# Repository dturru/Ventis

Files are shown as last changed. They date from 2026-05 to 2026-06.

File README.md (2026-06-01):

# Ventis

Smart window-ventilation device for dorm rooms. An ESP32 reads CO₂ / temperature / humidity
(SCD40), runs a control loop, and serves a phone-facing dashboard over its own WiFi AP. The
dashboard shows live air quality, trends, and a first-person AI mascot ("Dodi") that explains
what's happening and what the device is doing.

---

## Repo map

```
Ventis/
├── firmware/              ESP32 application (PlatformIO)
│   ├── src/main.cpp       sensors + control loop + web server + THE DASHBOARD (embedded)
│   ├── src/main_sim.cpp   simulation build variant
│   ├── include/           config.h, secrets.h.example  (copy to secrets.h, never commit secrets)
│   ├── platformio.ini     build config
│   └── wokwi.toml         Wokwi simulator config
├── dev/                   FRONTEND DEV HARNESS  ← do UI work here (no hardware needed)
│   ├── index.html         standalone copy of the dashboard
│   ├── serve.py           local server that mocks the device's HTTP endpoints
│   ├── mock-*.json        fake device data (data / history / insight)
│   ├── generate_mocks.py  regenerate the mock CO₂ story
│   └── README.md          dev-harness details
├── outdoor-node/          SEPARATE firmware for the outdoor sensor node (not the dashboard)
├── cad/                   hardware CAD
├── marketing/             posters, booth card
└── README.md              you are here
```

---

## `main.cpp` at a glance — what each block is

`firmware/src/main.cpp` is one file (~1,725 lines) but it's cleanly divided by
`// ── Section ──` header comments. Here's what each block is and its category:

| Lines | Section | What it does | Category |
|---|---|---|---|
| 1–18 | includes + helpers | libraries (WiFi, SCD40, SSD1306 OLED, async web server) + `toF()` | setup |
| 21–28 | **Sensors** | SCD40 / DS18B20 / OLED / web-server object declarations | sensors |
| 29–118 | **State** | global `readings` struct, mode switch, history ring buffer, insight timers | state |
| 119–177 | **Control logic** | fan decision (`evaluateFan`), duty %, **fan PWM output**, history push | control |
| 178–201 | **Google Sheets logger** | POSTs readings to the Sheets web-app for data logging | networking |
| 202–229 | **RGB LED** | CO₂-colored status LED — green / amber / red | hardware |
| 230–253 | **OLED** | draws the 128×64 status screen (CO₂, temp, fan, IP) | hardware |
| 254–466 | **/insight helpers** | builds Dodi's AI text; calls the Anthropic API (offline fallback if no key/WiFi) | backend (AI) |
| **469–1385** | **`INDEX_HTML`** | **the dashboard — HTML + CSS + JS served to phones** | **FRONTEND** |
| 1387–1537 | setupServer + auto-insight | HTTP routes: `/`, `/data`, `/history`, `/control`, `/insight`, `/log/*` | backend (API) |
| 1538–1639 | **Setup** | boot sequence: pin/PWM init, OLED, SCD40, DS18B20, **WiFi connect + AP**, start server | wifi / init |
| 1640–1725 | **Loop** | the heartbeat: read sensors → control → push history → log → redraw OLED → update LED | orchestration |

> Line numbers drift as the file is edited — jump by searching for the `// ── ` section headers
> (e.g. `// ── OLED ──`). **For UI work you only care about the one bold row (`INDEX_HTML`),** and
> even then you edit `dev/index.html`, not this file. Everything else is firmware/backend.

---

## Where the frontend lives (read this first)

This is an **embedded** project, so there is **no React app and no `src/components/` folder**.
The dashboard is a single hand-written HTML/CSS/vanilla-JS page that exists in **two places that
must be kept in sync**:

1. **`dev/index.html`** — the standalone, browser-runnable copy. **Do all UI work here.**
2. **`firmware/src/main.cpp`** — the canonical copy, embedded as a C++ string named `INDEX_HTML`
   (a `R"raw( ... )raw"` literal) that the ESP32 actually serves to phones. **Source of truth on
   the device.**

Inside `main.cpp`, the dashboard is the block from `INDEX_HTML[] PROGMEM = R"raw(` to
`</body></html>)raw";` (currently ~line 469 to ~line 1385). Within that block:

| Part | Find it by searching for |
|---|---|
| All CSS | `<style>` … `</style>` |
| HTML markup | between `</style>` and the first `<script>` |
| All JS (render, sidebar, trend chart, Dodi bubbles) | `<script>` … `</script>` |

> Search for those anchors rather than trusting line numbers — they shift as the file is edited.
> Everything **outside** that block in `main.cpp` is backend C++ (sensors, control loop, the AI
> `/insight` text generator ~line 254, and the `server.on(...)` HTTP routes ~line 1388). You do not
> need to touch any of it for UI work.

---

## Dev workflow (no hardware required)

```bash
cd dev
python serve.py
# open http://localhost:8000/?mock=1   (the ?mock=1 is required — it loads mock-*.json)
```

Edit `dev/index.html`, reload the browser, iterate. The mock server fakes every endpoint the page
calls, so the JS behaves exactly as it does on the device.

To change the demo CO₂ story (the numbers the page animates through), edit the curve functions in
`dev/generate_mocks.py`, run `python generate_mocks.py`, and reload.

### Getting your changes onto the device

There is **no build step that does this automatically.** When your UI is ready, copy the final HTML
from `dev/index.html` back into the `INDEX_HTML` block in `firmware/src/main.cpp` (between the
`R"raw(` and `)raw"` markers), then flash. Keep the two files identical. *(Automating this
round-trip is a known TODO.)*

---

## The endpoint contract (what the page talks to)

The JS in the dashboard calls these device endpoints. The dev server (`serve.py`) mocks all of them,
so you can develop against the same shapes:

| Endpoint | Method | Purpose |
|---|---|---|
| `/data` | GET | current readings (co2, tempIn, humidity, tempOut, fanOn, duty, logging state) |
| `/history` | GET | ring buffer of recent samples for the trend chart |
| `/insight` | GET / POST | the AI mascot's current text (GET) / regenerate it (POST) |
| `/control` | POST | manual override + setpoint (controller mode only) |
| `/log/start`, `/log/stop` | GET | start/stop Google-Sheets logging |

Control actions only fire from a controller session (the dashboard is opened with `?ctl=1`);
plain viewers are read-only. See `mock-data.json` / `mock-history.json` for exact field shapes.

---

## Branches & the booth fallback

- **`main`** — current dashboard + dev harness. **Branch off this.**
- **`booth-fallback`** (git tag) — the proven Technigala-booth build. If a change breaks the live
  demo, recover with `git checkout booth-fallback` and flash. It is not a branch; it is a permanent
  bookmark to the known-good commit.
- `dodi-pixel-art` — Dodi mascot sprite work.

---

## Firmware build (only when flashing real hardware)

PlatformIO project in `firmware/`. Copy `include/secrets.h.example` to `include/secrets.h` and fill
in WiFi + (optional) Anthropic API key before building. `platformio.ini` defines the board/env.
UI contributors do **not** need this — the `dev/` harness covers all dashboard work.

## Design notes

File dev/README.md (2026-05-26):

# Ventis dev — browser preview of the web UI

This folder lets you preview the Ventis web UI in a browser without flashing the ESP32. The `index.html` here is a copy of the `INDEX_HTML` PROGMEM string in `firmware/src/main.cpp`. The `serve.py` script is a tiny HTTP server that mocks the ESP32's endpoints (`/data`, `/history`, `/insight`, `/control`) so the JS behaves identically.

## Quick start

```bash
cd dev
python serve.py
```

Then open: <http://localhost:8000/?mock=1>

The `?mock=1` query parameter tells the JS to fetch from `/mock-*.json` files instead of the live device endpoints. Without it, the page tries to hit `/data` and `/history` (which the dev server doesn't serve as live endpoints), so always include it.

## Files

| File | Purpose |
|---|---|
| `index.html` | Standalone copy of the firmware web UI — must be kept in sync with the `INDEX_HTML` string in `firmware/src/main.cpp` |
| `serve.py` | Dev HTTP server (port 8000 by default; `python serve.py 8080` for custom port). Serves static files and fakes POST `/insight` + POST `/control` |
| `generate_mocks.py` | Regenerates the three mock JSON files. Run once, or whenever you want to tweak the demo CO2 narrative |
| `mock-data.json` | One current-readings snapshot (mirrors `GET /data`) |
| `mock-history.json` | 60-sample ring buffer with a CO2 narrative arc (baseline -> rise -> alarm -> recovery -> settle) — mirrors `GET /history` |
| `mock-insight.json` | Sample Claude API response (mirrors `POST /insight`) |

## Editing the demo CO2 story

Open `generate_mocks.py` and tweak the `co2_curve()`, `temp_curve()`, or `humidity_curve()` functions. Then:

```bash
python generate_mocks.py
```

Reload the browser to see the new story.

## Keeping `index.html` in sync with the firmware

If you edit the web UI in `firmware/src/main.cpp` (the `INDEX_HTML` PROGMEM string), copy the same HTML content into `dev/index.html` so the browser preview stays accurate. A future build-step refactor could auto-generate `index.html` from the firmware source; for now, manual sync.

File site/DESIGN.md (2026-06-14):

# Ventis — Design & Voice Guide

The design system and writing standard for the Ventis site (`site/`). This is
the source of truth: the site reads intentional, not vibe-coded, because the
decisions below are deliberate and documented. When you change the site, change
this doc too.

Tokens referenced here are defined in `src/global.css` (`:root`). Component
classes referenced here exist in that file. Keep the two in sync.

---

## 1. Brand & personality

Ventis makes an invisible problem visible and acts on it. The personality
follows from that:

- **Honest before impressive.** We show the negative control (East Wheelock),
  state the winter limitation, and never fabricate a number. Credibility is the
  product — the dataset and the candor are the moat.
- **Calm, technical, editorial.** Closer to a well-edited field report than a
  startup splash page. Confident, specific, unhurried.
- **Warm, not cute.** Dodi (the mascot) carries the warmth so the prose doesn't
  have to strain for it.

Tagline: **Senses · Ventilates · Explains.** Three verbs, in that order — it
also maps to the product loop and the How-It-Works page.

---

## 2. Voice & tone (also the copy standard)

The site's copy is strong when it's **specific and plain**. It drifts toward an
"AI-generated" feel when it leans on a few rhetorical crutches. Rules:

**Do**
- Lead with the concrete: a number, a room, a moment ("1,111 ppm in a Little
  Hall single, four hours past the line").
- Vary sentence length and rhythm. Let short declaratives land.
- Use plain connectives (period, comma, "and", "but") most of the time.
- Trust the reader. State the point once, well.

**Avoid (the AI-tells)**
- **Em-dashes: default to none in body copy.** This is the single biggest tell,
  and the bar is essentially zero, not "one per paragraph." Use a period, comma,
  colon, or the middot "·" for label separators (e.g. run names, the tagline). A
  rare em-dash in a citation is tolerable; if you're reaching for one in prose,
  restructure the sentence. (Run `grep -rn "—" site/src` before shipping copy.)
- **The "It's not X, it's Y" / "X vs. Y" antithesis on repeat.** It's punchy
  once per page. Three times is a tic. Vary it.
- **"honest / honestly" as a verbal crutch.** Demonstrate candor (show the
  negative control); don't keep announcing it. Aim for ≤1 use per page.
- **Triadic "no X, no Y, no Z" lists** more than once in a stretch.
- **Throat-clearing** ("It's important to note", "In today's world").
- **Generic startup-speak** ("seamless", "revolutionary", "game-changing",
  "we're on a mission").

**Mechanics**
- Curly quotes and apostrophes (`'` `'` `"` `"`), not straight.
- "CO₂" with subscript; "ppm" lowercase; "ASHRAE 1,000 ppm" as written.
- Numbers: thousands separators ("1,111 ppm"). Temperatures in °F on-screen.
- No emoji as UI or as bullets/eyebrows. Use the SVG icon set (§6).

**Claim integrity (non-negotiable)**
- Every CO₂ figure, citation, and product claim on the site must trace to real
  measured data or a cited source. Never round a measurement for punch. The
  data page numbers come from `runs.json` (generated by
  `scripts/extract_runs.py` from the real CSVs) — don't hand-edit them.
- Roadmap language: v2 = "first units expected Fall 2026" framed as a target,
  not a guarantee. No pricing anywhere.

---

## 3. Color

Defined in `:root`. Green is the brand; the CO₂ tiers are semantic and must keep
their meaning everywhere they appear.

**Brand greens** — `--green #1e6e3a` (primary), `--green-deep #155026`,
`--green-darker #0d4520`, `--green-soft #e8f5e9`, `--green-mist #f1f7f1`.

**Semantic air tiers** (CO₂ state — never repurpose these hues for decoration):
- Green `--green` — fresh / good (< ~800 ppm)
- Amber `--amber #b87900` (`--amber-soft #fff7e0`) — elevated / getting stuffy
- Red `--red #c6422c` (`--red-soft #fef2ef`) — high / over ASHRAE 1,000

**Neutrals** — `--bg #f4f7f3`, `--bone #faf9f6`, `--tile #ffffff`,
`--ink #16241a`, `--muted #5e6b5e`, `--faint #8a958a`, `--line` / `--line-soft`.

> The device-demo phone (`.device-screen`) re-scopes a slightly different token
> set to match the on-device app exactly (`--red #c62828`, `--border #d0dbd0`,
> etc.). That mismatch is intentional — it mirrors the ESP32 app, not the site.

**Contrast:** body and UI text must clear WCAG AA (4.5:1). `--muted` on `--tile`
passes; never put `--faint` on tinted fills for anything load-bearing.

---

## 4. Typography

Three roles, set in `:root`:

- **`--serif` DM Serif Display** — display only: hero wordmark, `.section-title`,
  `.evidence-title`, big stat numerals (`.point-k`). Never body.
- **`--sans` Outfit** — everything functional: body, lede, labels, buttons, nav.
- **`--mono` DM Mono** — data and machine voice: chart ticks, peak readouts,
  clocks, the device CO₂ number.

Scale uses `clamp()` for fluid sizing (see `.section-title`, `.lede`,
`.sticker-word`). Keep the eyebrow → title → lede rhythm at the top of each page.

---

## 5. Layout, spacing, elevation

- Container `.wrap` max-width `--maxw 1080px`; prose pages narrow to 860–900.
- Radii: **moderate** (`--r-lg 12 / --r-md 10 / --r-sm 8`, set 2026-06-13 "bolder pass" — dialed back from the all-`0` sharp experiment, which read as too many hard corners). Pills/chips/badges stay fully rounded (`999px`); device-demo phone + true circles unchanged. Elevation is **hairline-led**: crisper `--line` (0.16) + flatter resting shadows; lift on hover.
- Shadows: `--shadow-sm` / `--shadow` / `--shadow-lg` — soft, green-tinted, never
  harsh black. Elevation rises on hover, not at rest.
- Page rhythm: `eyebrow` (12px, tracked, green) → `section-title` → `lede`.

---

## 6. Components & iconography

Reusable primitives in `global.css`: `.panel` (hero nav cards), `.card`,
`.callout` (+ `.amber`), `.points-grid`/`.point`, `.evidence` block,
`.btn`/`.btn-primary`/`.btn-ghost`, `.flow` (how-it-works), `.cta-card`,
`.device-*` (demo).

**Icons:** custom Lucide-style SVGs via `components/Icon.tsx`, set in tinted
`.ico-badge` squares. **No emoji as icons** — this was a deliberate pass; don't
regress to emoji eyebrows or bullets.

---

## 7. Motion

- Transitions **150–300ms**, `ease`. Used for hover lift, tier color crossfades,
  bar fills.
- Entrances: `fade-up` on `.page`; the hero staggers (sticker→sub→air→actions→
  panels). Ambient: hero Dodi `dodi-float` (bob) + periodic **wing-flap & blink**
  (`dodi-wing-l/r`, `dodi-eyes`; reduced-motion-gated).
- **Scroll reveals** (`reveal-up`, §12): below-fold content on non-hero pages rises
  in as it enters the viewport, via CSS scroll-driven `animation-timeline: view()`
  (no JS). Wrapped in `@media (prefers-reduced-motion: no-preference)` +
  `@supports (animation-timeline: view())`, so it degrades to fully-visible — never
  a blank section. Hero + device demo excluded (they own their motion).
- Demo Dodi (`DodiMascot.tsx`) reacts to live state: breathing bob, emotion eyes
  (calm/alert/distress by CO₂ tier), wing-flap while the fan runs.
- **Always gate motion behind `@media (prefers-reduced-motion: reduce)`** — the
  Dodi animations already do. Any new looping animation must too.

---

## 8. Accessibility checklist (per change)

- [ ] Text contrast ≥ 4.5:1 (3:1 for ≥24px bold).
- [ ] Interactive elements are real `<button>`/`<a>`, keyboard-reachable, with a
      visible focus state. (Global `:focus-visible` square green ring lives in
      `global.css` as of 2026-06-13 §12; `accent-color: var(--green)` on native controls.)
- [ ] Images have descriptive `alt`; decorative SVGs `aria-hidden`.
- [ ] Looping/auto motion respects `prefers-reduced-motion`.
- [ ] Tap targets ≥ ~40px on the controls people actually use.

---

## 9. Pre-ship checklist

Adapted from the UI/UX pre-delivery discipline + Ventis specifics. Run before any
push to `main` (which auto-deploys to Vercel).

- [ ] `npm run build` passes (tsc + vite, no type errors).
- [ ] Render-verified in the browser at the route you changed — not just a green
      build. Check mobile width (≤640px) too.
- [ ] No emoji as icons; SVG icon set used.
- [ ] Transitions 150–300ms; reduced-motion respected.
- [ ] Contrast + focus states intact (§8).
- [ ] Responsive at 375 / 768 / 1024 / 1440.
- [ ] **Copy passes §2** — em-dash density low, no repeated "X vs Y", "honest"
      ≤1/page, no emoji eyebrows.
- [ ] **Every number and claim traces to real data / a cited source** (§2).
- [ ] No pricing; v2 framed as a Fall 2026 target.

---

## 10. Influences

Quality bar informed by the `ui-ux-pro-max-skill` pre-delivery checklist
(no-emoji-icons, 150–300ms transitions, 4.5:1 contrast, reduced-motion,
375/768/1024/1440 breakpoints) and anti-patterns (no AI purple/pink gradients;
no harsh neon). Ventis intentionally diverges toward a quiet editorial palette
rather than a trendy style — the credibility of the data is the aesthetic.

---

## 11. 2026-06-10 — craft pass + data-library parity

**Site (dialed-up field report):**
- **Hero air-moment** (`components/HeroAirMoment.tsx`, `.air-moment`): the one
  signature data element. A real measured overnight CO₂ rise (the Little Hall
  single, 1,111 ppm, ~4 h over the line) draws on, and the readout counts up from
  a calm baseline with its color crossing green to amber to red as it passes
  ASHRAE 1,000. Count-up and draw both honor `prefers-reduced-motion`. Numbers
  trace to real data (§2).
- **Paper grain** (`body::after`): a faint fractal-noise overlay over the air
  gradients for warmth and depth. **Warmer `--bone`** (`#faf8f2`).
- **Hero entrance stagger**: sticker → sub → air-moment → actions → panels, ~80ms
  apart; reduced-motion safe.
- **`.pullquote`**: serif editorial accent, available to prose pages.

**Data library (`library/`)** now shares this exact system (DM Serif / Outfit /
DM Mono, the semantic air tiers, the atmospheric backdrop, the card + shadow
language). It was a Vite starter (system font, purple accent, inline-styled
tables); it is now a branded data product with a glassy header, CO₂-tier run
chips, mono numerals, and editorial SOP pages. The same voice and claim-integrity
rules apply there. Tokens live in `library/src/theme.css`, kept in sync with this file.

---

## 12. 2026-06-13 — Impeccable craft layer

A second layer of design parameters, adopted from the Impeccable design skill
(`pbakaus/impeccable`). We take its **brand-agnostic craft discipline and
anti-slop bans** and **preserve our own brand** (green editorial; DM Serif /
Outfit / DM Mono; semantic air tiers). We do **not** adopt Impeccable's own
"Neo Kinpaku" gold/lacquer identity. Where Impeccable already overlaps §§3–10,
the existing rule stands; this section is only the *delta* plus two explicit
conflict resolutions. Apply it on every change, alongside the §9 pre-ship list.

### Deltas (new rules — not already covered above)

**Typography**
- **Line length 65–75ch** on any prose/body block. Add `max-width` in `ch` to
  long-text containers; don't let lede or paragraph copy run full-width.
- **`text-wrap: balance` on h1–h3**; **`text-wrap: pretty` on long prose** (kills
  orphans). Cheap, global, high-yield.
- **Display letter-spacing floor ≥ -0.04em.** Hero/`.section-title`/`.sticker-word`
  may tighten for optics but never below -0.04em (letters touch = cramped, not
  designed). The hero clamp ceiling is **≤ 6rem / 96px** — `.sticker-word` is at
  the limit (`clamp(52px,11vw,96px)`); hold it, don't raise.
- **Placeholder text needs 4.5:1 too** (same as body) — not the muted-gray default.

**Layout**
- **Cards are the lazy answer.** Reach for a card only when it's truly the best
  affordance. **Nested cards are always wrong** — flatten to sections, dividers,
  or tinted bands. Audit `.card`/`.panel` density on each page; if a grid is just
  identical icon+heading+text cards repeated, redesign the rhythm.
- Responsive grids without breakpoints: **`repeat(auto-fit, minmax(280px, 1fr))`.**
- **Semantic z-index scale** (in `:root`): dropdown → sticky → modal-backdrop →
  modal → toast → tooltip. **No arbitrary `999` / `9999`.**
- Flexbox for 1D, Grid for 2D. Don't default to Grid when `flex-wrap` works.

**Motion** (extends §7)
- Prefer **ease-out exponential** curves (`ease-out-quart/quint/expo`) over plain
  `ease` for entrances. **No bounce, no elastic.** Reduced-motion fallback stays
  mandatory (§7).
- Reveal animations must **enhance an already-visible default** — never gate
  content visibility on a class-triggered transition (it never fires on hidden
  tabs / headless renders → blank section).

### Absolute bans (match-and-refuse — rewrite the element if you're about to ship one)

- **Side-stripe borders** — `border-left/right` > 1px as a colored accent on cards,
  callouts, or alerts. Use full borders, background tints, or a leading icon/number.
  (Our `.callout.amber` must use a full tint/border, not a left stripe.)
- **Gradient text** (`background-clip:text` + gradient). Solid color; emphasis via
  weight/size.
- **Glassmorphism as default.** Permitted exactly where it already is and no more:
  the nav header (`global.css` `backdrop-filter`) + the library glassy header are
  "rare and purposeful." **Do not add new glass.**
- **The hero-metric template** (big number / small label / supporting stats /
  gradient accent). Our hero air-moment is a *real measured* signature element,
  not this SaaS cliché — keep it that way.
- **Identical card grids** repeated endlessly.
- **Numbered section markers as scaffolding** (`01 · About / 02 · Process`). Only
  when the section genuinely IS an ordered sequence.
- **Text that overflows its container** at any breakpoint. Test heading copy at
  375/768/1024/1440; if it overflows, lower the clamp max or rewrite the copy.

### Conflict resolutions (Impeccable vs. our existing system)

1. **Eyebrows — KEEP, with discipline.** Impeccable flags the tracked-uppercase
   eyebrow above *every section* as its #1 slop tell, but exempts "one named kicker
   as a deliberate brand system." Our eyebrow → title → lede is exactly that: a
   documented, page-level brand rhythm (§5). **Resolution:** the eyebrow stays as a
   **page-top** device. Do not sprinkle it above every sub-section within a page,
   and never let it be the *only* hierarchy signal. Audit pages with 2+ eyebrows.
2. **Glass — KEEP the two we have, freeze the count.** See the glassmorphism ban
   above: the nav + library headers are purposeful; no new instances.

### The AI-slop test (review heuristic for new work)

Before shipping a new page/section, run the category-reflex check at two altitudes:
- **First-order:** could someone guess the theme + palette from the category alone
  ("air-quality startup → green + clean")? If yes, the first reflex won.
- **Second-order:** could they guess it from category-plus-anti-reference
  ("air-quality but not generic-green → ...")? If yes, the trap one tier deeper won.
Our defensible answer is the **editorial field-report** posture (§1): the
credibility of the data is the aesthetic. Keep proof in front; don't let styling
hide it.

### 2026-06-13 — sharp-corner pass (bolder)

A deliberate move from soft to **sharp**: all radius tokens → `0`, and every
hardcoded rectangular radius squared (nav, buttons, icon badges, pills/tags →
square editorial tags, tooltip, hero sticker). This sharpens the field-report
posture and reads more technical/instrument-like.

- **Kept curved (intentional exceptions):** the device-demo phone frame + its
  internal UI (`.device-*` / `.dd-*`) because it represents physical hardware; a
  sharp "phone" reads as broken, not designed (same spirit as the §3 device-token
  exception). True circles (status dots, the round avatar) are circles, not
  corners — also kept.
- **Motion:** added `--ease-out: cubic-bezier(0.16, 1, 0.3, 1)` (ease-out-expo)
  and applied it to nav/button transitions. Sharp corners + crisp exponential
  motion cohere. Reduced-motion rules (§7) still apply.
- New default: **don't reintroduce `border-radius`** on rectangular surfaces. Use
  `var(--r-*)` (now 0) so the decision stays centralized.

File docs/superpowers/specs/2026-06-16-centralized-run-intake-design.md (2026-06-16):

# Centralized Run Intake — "Run Launcher" Design

**Date:** 2026-06-16
**Status:** Approved design (brainstorming → spec)
**Owner:** Diego (remote) / cofounder (on-campus operator)

## Problem

Starting a data-collection run today touches several disconnected surfaces:

1. The **condition label** is set on the device (telemetry `run`/`condition`) **and** typed again into the **consent** submission — independently.
2. `reconcile_consent.py` fuzzy-matches the two by `canonical(condition)` + nearest start time (±36 h).
3. When the two labels diverge (post-brownout restart re-typed a glued `oneperson`, etc.) the match fails → **orphaned consent**, the exact bug class fixed in PRs #15 and #25.

The operator also hops between the Google Sheet, the consent form, and manual run notes. We want **one gated submission** that records consent, sets the run condition, starts the device, and captures run notes — with the condition **single-sourced** so divergence is structurally impossible.

## Goals

- One cofounder-facing, gated action starts a fully-described, consented run.
- The condition label is composed once from structured fields and used for **both** the device control tab and the consent row → identical by construction → deterministic reconcile.
- A **preflight checkpoint gate** blocks a run when starting it would create a problem, but allows an **audited override** for problems that are safe to fix after the run (orphaned/deferred consent being the canonical case).
- Firmware is **unchanged** — it already polls the Apps Script control tab.

## Non-Goals

- Occupant self-serve / public form (operator is cofounder-only, behind Cloudflare Access).
- Changing how the device polls or how telemetry is written.
- Replacing `reconcile_consent.py` (it stays; it just stops failing because labels can't diverge).

## Architecture (Approach A — page in the gated `library/` app)

The Run Launcher lives in `library/`, which is already behind Cloudflare Access and already has Pages Functions talking to Supabase (`functions/api/annotate.ts`). No new deploy target or Access config.

```
[Cofounder phone]
  RunLauncherPage.tsx  (gated by Cloudflare Access)
        │ POST /api/run-launch  {fields, action, nonce, overrides[]}
        ▼
  functions/api/run-launch.ts  (Pages Function; holds secrets)
        │  1. compose canonical label (label.ts)
        │  2. preflight(...)  → verdicts (pure: preflight.ts)
        │  3. gate: hard-block abort | soft-block needs override | proceed
        │  4. insert consent  → Supabase (postgres.js)        [S3]
        │  5. start device    → Apps Script control doPost     (token)
        │  6. persist launch record (override flags + reason)
        ▼                                   ▼
  Supabase  consent_submissions      Google Sheet `control` tab
  + run_launches                      (logging, label, seq++)
                                            ▼ device polls doGet (existing)
                                      Device starts run, telemetry tagged
                                      with the SAME canonical label
```

### Components

| Component | Path | Responsibility |
|---|---|---|
| `RunLauncherPage.tsx` | `library/src/components/` | Form + live preflight checklist + Start/Stop. Visual/UX — see open questions. |
| `run-launch.ts` | `library/functions/api/` | Orchestrator: compose → preflight → gate → consent insert → device start → launch record. Holds `SUPABASE_DB_URL` + `CONTROL_TOKEN`. |
| `preflight.ts` | `library/functions/api/` | **Pure planner** (mirrors `plan_reconcile`): inputs → per-checkpoint verdicts + tier. Independently unit-tested. |
| `label.ts` | `library/src/lib/` + shared | Compose structured fields → canonical label; reject invalid combos. Mirrors `reconcile_consent.canonical()` rules so output is canonical by construction. |
| Apps Script control write | `firmware/sheets/Code.gs` | Extend `doPost` with `action:"control"`: token-auth (reuse `SHEETS_TOKEN`), set `control` tab `logging`/`label`, bump `seq`. Only genuinely new backend piece. |
| `run_launches` table | `site/scripts/supabase_schema.sql` | Audit row per launch: label, times, consent status, override flags + reason. The "needs attention" surface. |

## Canonical label (the divergence killer)

Structured fields → one string, used everywhere:

- **building** — dropdown of known buildings (`fahey`, `choates`, `little`, `east_wheelock`, …). Closed set.
- **scenario** — dropdown (`window`, `windowclosed`, `fan`, `baseline`, `negcontrol`, …). Closed set.
- **occupancy** — stepper emitting a **digit** (`1`, `2`, …) → `Nperson`. Never a spelled-out word.

Composed: `building_scenario_Nperson` (e.g. `fahey_window_1person`). The composed string must round-trip through the shared `canonical()` unchanged (a hard checkpoint). Because the *same* string is written to the control tab (→ device telemetry `condition`) and to `consent_submissions.condition`, `canonical()` of both is trivially equal and `match_run` is deterministic. The occupancy-as-digit rule encodes the convention from PR #25's follow-up directly into the UI.

## Preflight checkpoint gate

Run server-side in `preflight.ts`. Two tiers.

### Hard blocks — never overridable (cheap to fix, root-cause preventers)

- **H1 Authenticated** — `Cf-Access-Authenticated-User-Email` present (verified founder, as in `annotate.ts`).
- **H2 Valid canonical label** — building ∈ set, scenario ∈ set, occupancy is a positive integer; composed label round-trips through `canonical()` unchanged.
- **H3 Consent captured** — `attested_by`, `consent_method`, `terms_version` present (the *act* of consent is recorded; whether it *persists* is S3).

If any hard block fails: **abort with no mutation**, return what to fix. Start stays disabled.

### Soft blocks — overridable with explicit reason (logged, flags run for follow-up)

- **S1 Device online** — device posted telemetry within `DEVICE_FRESH_WINDOW` (default 90 s ≈ 3× the ~30 s cadence). Stale → telemetry may orphan. Override: device may catch the `seq` on reconnect.
- **S2 No active run** — control tab `logging` already true / a `run_id` active. Override: intentional restart (the post-brownout case).
- **S3 Consent persisted** — the Supabase insert succeeded. Failure (pooler timeout — LESSON (a)) → override "defer consent": start the run, flag consent pending, backfill later. **Reconcile links it automatically by the identical canonical label + time.** This is the override the user explicitly asked for.
- **S4 Duplicate guard** — identical canonical label launched within `DUP_WINDOW_H` (default 6 h). Override: legitimate repeat.

Override mechanics: each soft block surfaces in the form; the operator types a **reason** and confirms "Override & start." Every overridden run writes a `run_launches` row with the overridden checks + reason + timestamp, so it surfaces in a "needs attention" view (Curate/Coverage). **An override is a tracked follow-up, never a silent bypass.**

## Data flow & sequencing (orphan-safe)

1. Compose canonical label.
2. Run non-mutating checks: H1–H3, S1, S2, S4.
3. Attempt consent insert → result feeds S3.
4. **Gate:** any HARD fail → abort, no device start. Only SOFT fails and not overridden → abort, offer override. Clean or fully-overridden → proceed.
5. Start device: Apps Script control `doPost` (`logging=true`, `label`, `seq++`).
6. Persist `run_launches` record (label, started_at, device_last_seen, consent_status, override_flags, reason, nonce).

**Self-healing:** device-condition and consent-condition are the same canonical string, so `reconcile_consent` links them deterministically. Even a deferred-consent (S3 override) run reconciles automatically once consent is backfilled with that label. The divergence bug class is structurally impossible.

**Idempotency:** the client sends a launch `nonce`. Apps Script dedupes a repeated nonce (no double `seq` bump); consent insert dedupes on `(deployment_code, condition, recent agreed_at)`. Protects against double-submit / retries.

## Error handling

- **Apps Script start fails** (network/timeout): run NOT started; report to operator. If consent was already inserted it simply stays unreconciled until a matching run appears (or the operator retries) — harmless, self-heals. No orphan.
- **Supabase insert fails**: S3 soft block → defer-consent override path.
- **Partial failure** (consent ok, control fails): no orphan — consent without a run is an expected unreconciled row that links when the run later starts with the same label.
- **Apps Script control token invalid**: 401 from the endpoint; surfaced as a hard failure (misconfiguration), run not started.

## Security

- Form gated by Cloudflare Access; identity from `Cf-Access-Authenticated-User-Email`.
- Apps Script control write is token-authed with the existing `SHEETS_TOKEN` Script Property; the token lives only in the Pages Function env (`CONTROL_TOKEN`) — never shipped to the browser.
- No occupant PII: `attested_by` stays `occupant` or a founder pseudonym, per existing convention.

## Testing (TDD)

- **`preflight.ts`** (core): table of input states → expected verdicts + tiers (each hard/soft block, override resolution).
- **`label.ts`**: fields → canonical label; reject unknown building/scenario; enforce digit occupancy; assert round-trip equals `canonical()`.
- **`run-launch.ts`** (mock Supabase + Apps Script): clean start; hard-block abort (no mutation); soft-block-without-override abort; override path writes flags; partial-failure no-orphan; idempotent double-submit (same nonce).
- **Apps Script `doPost` control**: token reject; `seq` bump; start/stop set `logging` + `label`.
- Parity check: `label.ts` canonical output matches `reconcile_consent.canonical()` on a shared fixture set (prevents the TS and Python rules drifting).

## UX decisions (resolved 2026-06-16)

1. **Preflight panel** — hard blocks render **red** and disable Start; soft blocks render **amber** with an inline reason field + "Override & start."
2. **Start flow** — a single **Start run** button runs preflight, then either starts or reveals blocks/overrides inline (no separate preflight click).
3. **Stop-run notes** — Stop ends the run immediately; an **optional** notes field captures door/placement notes when available (appended via the existing annotate path). Never blocks ending a run.
4. **Dropdown contents** (editable defaults; `other` always falls back to a free-text field that must pass `canonical()` validation):
   - **building:** `fahey`, `choates`, `little`, `east_wheelock`, `mid_mass`, `summit`, `apt`, `other`
   - **scenario:** `baseline`, `window`, `windowclosed`, `fan`, `fan_window`, `negcontrol`, `other`
   - **occupancy:** stepper, integer ≥ 0, emitted as `Nperson`

## Rollout

- Additive only; firmware untouched. Ships when the `library/` app redeploys (Cloudflare Pages).
- Sequence: schema (`run_launches`) → Apps Script control `doPost` + Script Property/env wiring → `label.ts`/`preflight.ts` (pure, TDD) → `run-launch.ts` → `RunLauncherPage.tsx` → manual end-to-end with a real device.

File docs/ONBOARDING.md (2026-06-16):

# Ventis — Onboarding Guide

> Auto-generated from the project knowledge graph (`/understand`), commit `2e7051dc`, 2026-06-16.
> 342 nodes · 493 edges · 8 architecture layers · 14-step guided tour.

## 1. Project Overview

**Ventis** is a smart window-ventilation device for dorm rooms. An **ESP32** reads CO₂, temperature, and humidity from an **SCD40** sensor, runs a ventilation control loop, and serves a phone-facing dashboard over its **own WiFi access point** — showing live air quality, trends, and a first-person AI mascot (**"Dodi"**) that explains what the device is doing.

The device *is* the product. Everything else in this monorepo exists to **support, prove, or analyze** what the firmware does.

- **Core languages:** C++ (firmware), TypeScript/React (3 web apps), Python (data pipeline), SQL (Supabase schema), plus Apps Script, HTML/CSS, YAML.
- **Frameworks/tooling:** React · Vite · Vitest · Arduino · PlatformIO · Recharts · Cloudflare Pages · Wrangler · Vercel · GitHub Actions.
- **Repo shape:** ESP32/PlatformIO firmware + outdoor sensor node + three React+Vite+TS web apps (public site, gated data library, on-device dashboard) + a Python ETL pipeline feeding a Supabase system-of-record.

> ⚠️ 189 source files — when running incremental analysis or focused work, scope to a subdirectory.

## 2. Architecture Layers

The repo has **no common source prefix** — top-level directories are the module seams, and each is largely self-contained (intra-module imports only). The 8 layers:

| Layer | Dir(s) | What it is |
|---|---|---|
| **Embedded Firmware** | `firmware/`, `outdoor-node/` | ESP32/ESP32-C3 Arduino firmware: sensor reads, control loop, LittleFS-served UI, Apps Script telemetry bridge. |
| **On-Device Dashboard App** | `app/` | React/Vite phone dashboard served by the device over its WiFi AP. Compiles down to the firmware's LittleFS bundle. |
| **Marketing & Proof Site** | `site/src`, `site/api`, `site/functions` | Public React site telling the Ventis story to institutional contacts + beta students; serverless consent capture. |
| **Gated Data Library** | `library/` | Gated React app (Cloudflare Access) to browse/compare/export collected run datasets. |
| **Data Pipeline & Schema** | `site/scripts/`, root `*.py` | Python ETL (Sheet → Supabase → catalog) + the Supabase SQL schema = the data moat. |
| **Infrastructure & CI/CD** | `.github/workflows`, root config | GitHub Actions jobs that run the whole data path hourly; Cloudflare/Wrangler deploy config. |
| **Documentation** | `docs/`, READMEs | Design docs, phased implementation plans, specs, marketing artifacts. |
| **CAD & Dev Tooling** | `cad/`, `dev/` | Fusion 360 enclosure scripts + the local dev harness that mocks the device so UI work needs no hardware. |

## 3. Key Concepts & Design Decisions

- **The device is self-contained.** The firmware serves its own dashboard from LittleFS so a phone connects directly to the device's AP with **no internet**. The React `app/` is authored separately and *compiled down* into the firmware's embedded `data/` bundle.
- **One dashboard, two homes.** `dev/index.html` is a standalone browser copy of the firmware's embedded UI. **They must stay in sync** — the dev harness mirrors `INDEX_HTML` in `firmware/src/main.cpp`. This is a recurring footgun; see `dev/README.md`.
- **Data flows strictly outward:** device → Apps Script → locked Google Sheet → Python ETL → Supabase (system-of-record) → catalog.json → gated library. The public site only *writes back* consent.
- **The dataset is the moat.** Supabase is the durable system-of-record; consent is enforced at the schema level (`consent` / `consent_submissions`) so every logging run is auditable and opt-in.
- **Types-first UI.** `app/src/types.ts` and `library/src/lib/catalog.ts` are the highest-fan-in modules in their apps — read them first to learn the vocabulary the rest of the code speaks.
- **Dodi is a first-class feature**, not decoration — the mascot's mood/pose states are wired through the live view to explain air quality in plain language.

## 4. Guided Tour (recommended reading order)

Follow the firmware outward — the data flow is the spine of the project.

1. **Project Overview** — `README.md`. The mental model: device-as-product, dashboard over its own AP.
2. **Firmware Entry Point** — `firmware/src/main.cpp`. The heart: SCD40 reads, control loop, web server, embedded dashboard. High fan-in.
3. **Hardware Config & Build** — `firmware/include/config.h` (pins + thresholds), `firmware/platformio.ini` (real ESP32 over COM6 + Wokwi sim env, pinned sensor libs).
4. **The Embedded Dashboard** — `firmware/data/index.html`. The built UI baked into LittleFS; what the user actually sees.
5. **Dashboard Source: Shell & Types** — `app/src/App.tsx` (hooks + bottom-nav + Dodi across Live/Trends/Controls), `app/src/types.ts` (most-depended-upon module).
6. **API & Hooks** — `app/src/api.ts` (live data/history/insight + mock fallback), `useSensorData`, `useTier`. The bridge between control loop and UI.
7. **Live View & Dodi** — `app/src/views/LiveView.tsx` (highest fan-out), `app/src/components/DodiMascot.tsx`.
8. **The Dev Harness** — `dev/serve.py` (mocks `/data`, `/history`, `/insight`), `dev/README.md`. Where day-to-day UI work happens.
9. **Telemetry Bridge** — `firmware/sheets/Code.gs` (device POSTs → locked Sheet), `docs/ventis-sheet-guide.md`.
10. **The Data Pipeline (ETL)** — `site/scripts/sheet_source.py` → `supabase_sync.py` → `build_catalog.py`.
11. **The Database Schema** — `site/scripts/supabase_schema.sql`: `readings`, `runs`, `consent`/`consent_submissions`.
12. **The Gated Data Library** — `library/src/App.tsx`, `library/src/lib/catalog.ts` (repo's single highest-fan-in module), `RunTable.tsx`.
13. **The Marketing & Proof Site** — `site/src/App.tsx`, `site/src/pages/Proof.tsx`, `site/api/consent.ts`.
14. **CI/CD Capstone** — `.github/workflows/data-library.yml`: hourly pull → sync → reconcile consent → rebuild catalog → deploy library.

## 5. File Map (key files by layer)

**Embedded Firmware**
- `firmware/src/main.cpp` — primary firmware: sensors, fan control, Sheets telemetry, web UI, control polling.
- `firmware/src/main_sim.cpp` — sim build driving synthetic readings through the same control/web paths.
- `firmware/sheets/Code.gs` — Apps Script web-app receiving device POSTs into the locked Sheet.
- `firmware/data/index.html` + `data/assets/*` — built React UI served from LittleFS.
- `outdoor-node/src/main.cpp` — battery outdoor temp node (wake → read DS18B20 → report → sleep).

**On-Device Dashboard App** (`app/`)
- `App.tsx` (complex) — shell wiring hooks, routing, mascot.
- `types.ts` — shared sensor/history/control payload shapes (highest fan-in).
- `api.ts` + `hooks/useSensorData.ts` + `hooks/useTier.ts` — device API bridge.
- `views/LiveView.tsx`, `TrendsView.tsx`, `ControlsView.tsx` — the three screens.
- `components/DodiMascot.tsx`, `DormPicker.tsx`, `TourOverlay.tsx` — mascot + UI.

**Marketing & Proof Site** (`site/`)
- `src/App.tsx` — route table; `src/pages/Proof.tsx` — flagship CO₂ run + chart.
- `api/consent.ts` — serverless consent capture (feeds `consent_submissions`).
- `src/components/DeviceDemo.tsx` (complex) — interactive recorded-run playback.
- `DESIGN.md` — brand/voice/motion design canon.

**Gated Data Library** (`library/`)
- `src/lib/catalog.ts` — core data layer; load/filter/search/sort (repo-wide highest fan-in).
- `src/components/RunTable.tsx`, `ComparePage.tsx`, `CoveragePage.tsx`, `CuratePage.tsx` — the pages.
- `src/lib/coverage.ts` — occupancy/building coverage analytics + collection priorities.
- `functions/api/annotate.ts` — Cloudflare Pages function for run annotations.

**Data Pipeline & Schema** (`site/scripts/`)
- `build_catalog.py` (complex) — fetch runs (Supabase/SQLite), parse condition labels, merge consent → `catalog.json`.
- `extract_runs.py` / `archive_runs.py` — ingest + bucketize raw readings into runs.
- `annotate.py`, `reconcile_consent.py`, `supabase_sync.py`, `sheet_source.py` — the ETL + governance tools.
- `supabase_schema.sql` — the system-of-record schema.
- `tests/test_build_catalog.py` — label-parse + catalog emission tests.

**Infrastructure & CI/CD**
- `.github/workflows/data-library.yml` — the hourly pipeline (pull → sync → reconcile → catalog → deploy).

**CAD & Dev Tooling**
- `dev/serve.py`, `dev/index.html`, `dev/generate_mocks.py` — the no-hardware UI dev loop.
- `cad/split_enclosure.py` — Fusion 360 enclosure split for printing.

## 6. Complexity Hotspots — approach carefully

| File | Why |
|---|-----|
| `firmware/src/main.cpp` | Does everything on-device (sensors + control + telemetry + web server). Central; changes ripple. |
| `app/src/App.tsx` & `views/LiveView.tsx` | Highest fan-in/fan-out in the dashboard; the composition hub. |
| `app/src/components/DodiMascot.tsx` | Stateful animated SVG with mood/pose logic used everywhere. |
| `library/src/lib/catalog.ts` & `coverage.ts` | The library's data + analytics core; every page depends on it. |
| `library/src/components/RunTable.tsx` / `CoveragePage.tsx` | Heavy filtering/sorting/visualization. |
| `site/scripts/build_catalog.py` | Label parsing + multi-source merge + consent join; the ETL keystone (well-tested — lean on the tests). |
| `site/src/components/DeviceDemo.tsx` | Time-driven animation state machine. |
| `dev/index.html` ↔ `firmware/src/main.cpp` `INDEX_HTML` | Must stay in sync by hand — easy to drift. |

## 7. Getting Started

- **UI work?** Start in `dev/` — `python dev/serve.py` mocks the device endpoints so you never need to flash hardware. Keep `dev/index.html` in sync with the firmware's embedded UI.
- **Firmware?** PlatformIO; two envs in `firmware/platformio.ini` (real ESP32 over COM6, Wokwi sim). Copy `include/secrets.h.example` → `secrets.h` (never commit it).
- **Data/pipeline?** `site/scripts/` Python; run the tests first to understand label parsing. Supabase is the source of record.
- **Explore interactively:** run `/understand-dashboard` to open the graph visualizer.

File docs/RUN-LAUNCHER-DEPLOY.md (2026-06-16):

# Run Launcher — Deploy Runbook (Task 8)

This is the manual gate before merging PR #27. All code (Tasks 1–7) is on `feat-run-launcher`.
Do these four steps in order, on a machine with the device reachable.

## 1. Apply the database migration

The launcher writes an audit row per launch. Create the table in Supabase.

- Open the Supabase project → **SQL editor** → paste and run the `run_launches` block from
  `site/scripts/supabase_schema.sql` (the last `create table if not exists run_launches (...)`
  plus its `create index`). It is idempotent — safe to re-run.
- Verify: `select * from run_launches limit 1;` returns no error (0 rows is fine).

## 2. Deploy the updated Apps Script

The launcher starts/stops the device by POSTing to the Apps Script control endpoint, and
reads device liveness from it.

- Open the Apps Script project bound to the telemetry Sheet.
- Sync the updated `firmware/sheets/Code.gs` (paste it in, or `clasp push` if configured).
- **Deploy → Manage deployments → edit the active deployment → New version → Deploy.**
  Keep the SAME `/exec` URL (no firmware reflash needed).
- Verify GET (liveness):
  `curl -s "<EXEC_URL>"` → JSON includes `lastTelemetryAt` (an ISO timestamp or null).
- Verify the token is set: in the Apps Script project, **Project Settings → Script properties**
  must contain `SHEETS_TOKEN`. If unset, set it now (any strong random string) — note the value
  for step 3.
- Verify control write (replace TOKEN + URL):
  `curl -s -X POST "<EXEC_URL>" -H 'Content-Type: application/json' -d '{"token":"<SHEETS_TOKEN>","action":"control","logging":false,"label":"test_window_1person"}'`
  → `{"ok":true,"seq":<n>}` and the Sheet's `control` tab row updates. A wrong token returns
  `{"ok":false,"error":"unauthorized"}`.

## 3. Set Cloudflare Pages environment variables

The `run-launch` Pages Function needs three secrets (Production environment of the
`ventis-data-library` Pages project → Settings → Environment variables):

| Variable | Value |
|---|---|
| `CONTROL_URL` | the Apps Script `/exec` URL from step 2 |
| `CONTROL_TOKEN` | the **same** value as the Apps Script `SHEETS_TOKEN` script property |
| `SUPABASE_DB_URL` | already set — **confirm it is the 6543 transaction-pooler URL**, not 5432 (5432 times out from Cloudflare) |

Redeploy the Pages project (or it picks the vars up on the next deploy from the merged branch).

## 4. Real-device dry run

With the device powered and online, open `/launch` (behind Cloudflare Access) and walk:

1. **Clean start** — pick building/scenario/occupancy (try a word like `two` to confirm it
   parses), fill consent, click **Start run** → status "started". Within the device poll
   interval, confirm telemetry rows appear tagged with the exact label (e.g. `fahey_window_2person`).
2. **Stop** — click **Stop run** → device stops logging.
3. **Soft-block override** — power the device off, **Start run** again → amber `device_online`
   check with its explanation; tick override + type a reason → "Override & start" succeeds and
   writes a `run_launches` row with `override_flags = {device_online}` and your reason.
4. **Defer consent** (optional, on a preview deploy) — point `SUPABASE_DB_URL` at a bad value,
   Start → amber `consent_persisted`; override → run starts with `consent_status = deferred`;
   restore the env and confirm `reconcile_consent.py` links it once consent is backfilled (same
   `canonical_label`).
5. **Reconcile parity** — `cd site/scripts && python -m pytest tests/ -q` → all pass.

## Done

When steps 1–4 pass, the launcher is live end-to-end. Merge PR #27.

> Notes: firmware is unchanged (it already polls the control tab). `.understand-anything/`
> and `dist/` stay gitignored. The control token never reaches the browser — it lives only in
> the Apps Script script property and the Cloudflare Function env.

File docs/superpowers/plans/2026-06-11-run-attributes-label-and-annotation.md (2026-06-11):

# Run Attributes: Label Scenario + Annotation Overrides — Implementation Plan

> **For agentic workers:** REQUIRED SUB-SKILL: Use superpowers:subagent-driven-development or superpowers:executing-plans to implement this plan task-by-task. Steps use checkbox (`- [ ]`) syntax.

**Goal:** Populate each catalog run's ventilation attributes from its label (with sensible defaults), and let an annotation override any attribute when reality differs from the label. So `little_window_1_person` shows "window open · fan off, 1 occupant" from the label, and its annotation override bumps occupancy to 2 (roommate moved in).

**Architecture:** `build_catalog` derives `window` / `fan` / `scenario` from the condition label (occupancy already parsed — see "Done already"). The `annotations` table gains nullable override columns (`occupancy`, `window`, `fan`); `build_catalog` resolves **annotation override > label default** and recomposes the scenario. The catalog UI shows the resolved attributes and marks which were set by annotation.

**Tech Stack:** Python (build_catalog, annotate, pytest), Supabase Postgres (annotations table), React/TS/Vite (the `library/` catalog), vitest.

---

## Context for a fresh session (read first)

- Repo: `C:\Users\turru\Projects\ventis`. Catalog app: `library/`. Pipeline/scripts: `site/scripts/`.
- **Supabase from the cloud uses port 6543** (transaction pooler), not 5432 — see `docs/cloud-connection-and-deploy.md`. The live `SUPABASE_DB_URL` (6543) is in the gitignored `library/.dev.vars` on this machine; read it from there for any local DB op (don't echo it).
- **DDL / one-off DB ops:** Diego runs them in the **Supabase SQL editor** (browser) — provide him the SQL. Annotation values are set via SQL / `annotate.py` CLI / Supabase Table Editor (the `/curate` web page exists but is plan-gated by Cloudflare's free-tier subrequest limit — out of scope here).
- **Design/voice (`site/DESIGN.md`):** the catalog shares the site's system. Use the middot `·` as a separator, **no em-dashes** in any copy. Run `npm run build` + vitest before shipping.
- **build_catalog merge point:** `site/scripts/build_catalog.py` ~line 178 does `from annotate import load_annotations, merge_annotations; merge_annotations(records, load_annotations())`. `merge_annotations` (in `annotate.py`) currently copies note/quality_flag/tags onto each record.
- **`annotate.py`:** `COLS = ["run_key","note","quality_flag","tags","updated_by"]`; PG load = `select run_key, note, quality_flag, tags, updated_by from annotations`; `_upsert_pg` inserts those; CSV `STORE` = `archive/annotations.csv` (local fallback). CLI: `--set <run_key> --note --flag --tags --by`.
- **`Run` interface:** `library/src/lib/catalog.ts` (has `occupancy: number|null`, `window_state: string`, `note?`, `quality_flag?`, `tags?`, …).
- **UI:** `RunDetail.tsx` renders a rows array (e.g. `["Occupancy", run.occupancy ?? "·"]`, `["Window", run.window_state || "·"]`). `RunTable.tsx` has `COLS` (Building / Occ / Condition) + cell rendering.

### Done already (do NOT redo)
Occupancy label parsing is fixed and shipped (commit `94346e7`): `_occupancy` in `build_catalog.py` now handles `1_person`, `1p`, word-numbers, and single/double/triple room types. 45 pytest green. This plan builds on it.

### Decisions locked
- Window default is **blank** when the label is silent (do NOT assert closed). Fan default is **off** unless the label names a fan.
- Annotation overrides are **structured columns**, not free-text note parsing.
- `window_state` (logged sensor field) stays as-is; the new label-derived field is named **`window`**. Keep them distinct.

---

## Phase 1 — Label-derived scenario (Python)

### Task 1: window / fan / scenario parsers in build_catalog (TDD)

**Files:** Modify `site/scripts/build_catalog.py`; Test `site/scripts/tests/test_build_catalog.py`

- [ ] **Step 1: Write failing tests**

Add to `site/scripts/tests/test_build_catalog.py`:

```python
from build_catalog import window_from_label, fan_from_label, compose_scenario

def _toks(s):
    import re
    return [t for t in re.split(r"[^a-z0-9]+", str(s).lower()) if t]

def test_window_from_label():
    assert window_from_label(_toks("little_window_1_person")) == "open"
    assert window_from_label(_toks("midmass_windowfan_3person")) == "open"
    assert window_from_label(_toks("eastwheelock_fanclosed_2person")) == "closed"
    assert window_from_label(_toks("little_baseline_1person")) == "closed"
    assert window_from_label(_toks("1RSingle - Fahey")) == ""        # silent -> blank
    assert window_from_label(_toks("Judge_3RDouble")) == ""          # silent -> blank

def test_fan_from_label():
    assert fan_from_label(_toks("eastwheelock_fanclosed_2person")) == "on"
    assert fan_from_label(_toks("midmass_windowfan_3person")) == "on"
    assert fan_from_label(_toks("little_window_1_person")) == "off"  # default off
    assert fan_from_label(_toks("1RSingle - Fahey")) == "off"

def test_compose_scenario():
    assert compose_scenario("open", "off") == "window open · fan off"
    assert compose_scenario("closed", "on") == "window closed · fan on"
    assert compose_scenario("", "off") == "fan off"                  # window unknown -> omit
    assert compose_scenario("open→closed→open", "off") == "window open→closed→open · fan off"
```

- [ ] **Step 2: Run, expect failure**

`cd site/scripts && python -m pytest tests/test_build_catalog.py -q` → FAIL (ImportError: cannot import `window_from_label`).

- [ ] **Step 3: Implement the parsers**

In `site/scripts/build_catalog.py`, just below `_occupancy` (after the `ROOM_TYPE`/`PERSON_TOK` block), add:

```python
_WINDOW_OPEN = {"window", "windowopen", "windowfan", "open"}
_WINDOW_CLOSED = {"closed", "fanclosed", "baseline"}

def window_from_label(toks):
    """'open' / 'closed' / '' — never assert when the label is silent (blank)."""
    if any(t in _WINDOW_OPEN for t in toks):
        return "open"
    if any(t in _WINDOW_CLOSED for t in toks):
        return "closed"
    return ""

def fan_from_label(toks):
    """A fan is OFF unless the label names one (any token containing 'fan')."""
    return "on" if any("fan" in t for t in toks) else "off"

def compose_scenario(window, fan):
    """Readable ventilation descriptor. Window omitted when unknown; fan always shown."""
    parts = []
    if window:
        parts.append(f"window {window}")
    parts.append(f"fan {fan}")
    return " · ".join(parts)
```

- [ ] **Step 4: Run, expect pass**

`python -m pytest tests/test_build_catalog.py -q` → all PASS.

- [ ] **Step 5: Commit**

```bash
git add site/scripts/build_catalog.py site/scripts/tests/test_build_catalog.py
git commit -m "feat(ventis): parse window/fan/scenario from run label (fan off default, window blank when silent)"
```

### Task 2: emit window / fan / scenario in run_record (TDD)

**Files:** Modify `site/scripts/build_catalog.py`; Test same file.

- [ ] **Step 1: Failing test** — add:

```python
def test_run_record_emits_label_scenario():
    rec = run_record({"run_key": "k", "condition": "little_window_1_person",
                      "start": "2026-06-10 17:48:00", "end": "2026-06-11 00:00:00"})
    assert rec["window"] == "open"
    assert rec["fan"] == "off"
    assert rec["scenario"] == "window open · fan off"
    assert rec["occupancy"] == 1
    assert rec["window_state"] == ""   # logged field untouched
```

- [ ] **Step 2: Run → FAIL** (KeyError 'window').

- [ ] **Step 3: Implement** — in `run_record` (after `lab = parse_label(...)`), compute and add to the returned dict. Replace the occupancy/window_state lines:

```python
    lab = parse_label(run.get("condition", ""))
    toks = [t for t in re.split(r"[^a-z0-9]+", str(run.get("condition", "")).lower()) if t]
    window = window_from_label(toks)
    fan = fan_from_label(toks)
```

and in the returned dict add these keys alongside `occupancy`:

```python
        "occupancy": lab["occupancy"],
        "window": window,
        "fan": fan,
        "scenario": compose_scenario(window, fan),
        "window_state": run.get("window_state", ""),
```

- [ ] **Step 4: Run → PASS** (and full suite: `python -m pytest tests/ -q`).

- [ ] **Step 5: Commit**

```bash
git add site/scripts/build_catalog.py site/scripts/tests/test_build_catalog.py
git commit -m "feat(ventis): emit label-derived window/fan/scenario on each run record"
```

---

## Phase 2 — Annotation override columns

### Task 3: schema — add override columns (Diego runs DDL)

**Files:** Modify `site/scripts/supabase_schema.sql` (documentation); produce SQL for Diego.

- [ ] **Step 1: Update the schema doc** — in `supabase_schema.sql`, extend the `annotations` table definition:

```sql
create table if not exists annotations (
  run_key      text primary key,
  note         text,
  quality_flag text,                 -- good | caution | exclude (else: no flag)
  tags         text,                  -- optional, comma-separated
  occupancy    int,                   -- override: actual occupancy when label is wrong
  window       text,                  -- override: open | closed | free text (e.g. open→closed→open)
  fan          text,                  -- override: on | off
  updated_by   text,                  -- founder pseudonym, never an occupant
  updated_at   timestamptz default now()
);
```

- [ ] **Step 2: Hand Diego the live ALTER** (he runs it in the Supabase SQL editor — `create table` won't alter an existing table):

```sql
alter table annotations
  add column if not exists occupancy int,
  add column if not exists window text,
  add column if not exists fan text;
```

- [ ] **Step 3: Commit** the schema doc:

```bash
git add site/scripts/supabase_schema.sql
git commit -m "docs(ventis): annotations override columns (occupancy/window/fan)"
```

### Task 4: annotate.py — carry + write the override fields (TDD)

**Files:** Modify `site/scripts/annotate.py`; Test `site/scripts/tests/test_annotate.py` (create if absent, else extend).

- [ ] **Step 1: Failing test** — exercise the CSV (no-DB) path:

```python
def test_upsert_carries_override_fields(tmp_path):
    import annotate
    store = tmp_path / "annotations.csv"
    annotate.upsert_annotation(
        {"run_key": "k1", "note": "roommate moved in", "quality_flag": "caution",
         "tags": "occupancy-change", "occupancy": "2", "window": "open", "fan": "off",
         "updated_by": "diego"},
        path=str(store), db_url="")
    annos = annotate.load_annotations(path=str(store), db_url="")
    assert annos["k1"]["occupancy"] == "2"
    assert annos["k1"]["window"] == "open"
    assert annos["k1"]["fan"] == "off"
```

- [ ] **Step 2: Run → FAIL** (override keys dropped — not in `COLS`).

- [ ] **Step 3: Implement** in `annotate.py`:
  - Extend `COLS`: `["run_key","note","quality_flag","tags","occupancy","window","fan","updated_by"]`.
  - `_load_annotations_pg`: change the select to `select run_key, note, quality_flag, tags, occupancy, window, fan, updated_by from annotations`. (Quote `window` if needed: `"window"` — it's a reserved-ish word; use `select … , occupancy, "window", fan, …`.)
  - `_upsert_pg`: update the insert column list + `on conflict` set to include `occupancy, "window", fan`. Map params for all `COLS`.
  - CLI `main`: add `--occupancy`, `--window`, `--fan` flags to the `rec` built under `--set`, mirroring `--note`.

- [ ] **Step 4: Run → PASS**. Also run the PG-independent suite: `python -m pytest tests/ -q`.

- [ ] **Step 5: Commit**

```bash
git add site/scripts/annotate.py site/scripts/tests/test_annotate.py
git commit -m "feat(ventis): annotate.py carries occupancy/window/fan override fields"
```

---

## Phase 3 — Resolution (override > label) in build_catalog

### Task 5: resolve overrides + recompose scenario (TDD)

**Files:** Modify `site/scripts/build_catalog.py`; Test same.

- [ ] **Step 1: Failing test** — a small pure resolver:

```python
from build_catalog import apply_attr_overrides

def test_apply_attr_overrides():
    rec = {"run_key": "k", "occupancy": 1, "window": "open", "fan": "off",
           "scenario": "window open · fan off"}
    anno = {"occupancy": "2", "window": "", "fan": ""}   # only occupancy overridden
    out = apply_attr_overrides(rec, anno)
    assert out["occupancy"] == 2            # coerced to int, from annotation
    assert out["window"] == "open"          # blank override = keep label value
    assert out["scenario"] == "window open · fan off"
    assert out["attr_overrides"] == ["occupancy"]
```

- [ ] **Step 2: Run → FAIL** (ImportError).

- [ ] **Step 3: Implement** `apply_attr_overrides` in `build_catalog.py`:

```python
def apply_attr_overrides(rec, anno):
    """Annotation override wins over the label-derived value, per field. A blank/None
    override means 'no override' (keep the label value). Records which fields were
    overridden in rec['attr_overrides'] so the UI can mark them. Recomposes scenario."""
    overridden = []
    occ = anno.get("occupancy")
    if occ not in (None, "", "None"):
        rec["occupancy"] = int(occ); overridden.append("occupancy")
    for f in ("window", "fan"):
        v = anno.get(f)
        if v not in (None, "", "None"):
            rec[f] = v; overridden.append(f)
    rec["scenario"] = compose_scenario(rec.get("window", ""), rec.get("fan", "off"))
    rec["attr_overrides"] = overridden
    return rec
```

- [ ] **Step 4: Wire it into the merge** — at the build_catalog annotation merge site (~line 178), after `merge_annotations(records, annos)`:

```python
        annos = load_annotations()
        merge_annotations(records, annos)              # note/quality_flag/tags
        for r in records:
            apply_attr_overrides(r, annos.get(r["run_key"], {}))
```

(Adjust to the existing variable names; `load_annotations()` is already called once — reuse that result instead of calling twice.)

- [ ] **Step 5: Run → PASS** + full suite green.

- [ ] **Step 6: Commit**

```bash
git add site/scripts/build_catalog.py site/scripts/tests/test_build_catalog.py
git commit -m "feat(ventis): resolve annotation overrides over label defaults + recompose scenario"
```

---

## Phase 4 — Catalog UI

### Task 6: Run interface fields

**Files:** Modify `library/src/lib/catalog.ts`

- [ ] Add to the `Run` interface:

```ts
  window?: string;       // label-derived (or annotation-overridden) window: open | closed | ""
  fan?: string;          // on | off
  scenario?: string;     // "window open · fan off"
  attr_overrides?: string[];  // which attrs came from the annotation
```

- [ ] Commit: `git add library/src/lib/catalog.ts && git commit -m "feat(ventis): Run interface gains window/fan/scenario/attr_overrides"`

### Task 7: RunDetail — show scenario + mark overrides

**Files:** Modify `library/src/components/RunDetail.tsx`

- [ ] In the rows array, replace the `["Occupancy", …]` / `["Window", …]` rows with resolved + label-derived values, and add Scenario + Fan. Mark annotation-sourced fields with a small "(noted)" suffix when `run.attr_overrides?.includes(field)`:

```tsx
    const noted = (f: string) => (run.attr_overrides?.includes(f) ? " (noted)" : "");
    // ...
    ["Scenario", run.scenario || "·"],
    ["Occupancy", (run.occupancy ?? "·") + noted("occupancy")],
    ["Window", (run.window || "·") + noted("window")],
    ["Fan", (run.fan || "·") + noted("fan")],
    ["Window (logged)", run.window_state || "·"],
```

- [ ] Type-check (`cd library && npx tsc -b --noEmit`) + commit.

### Task 8: RunTable — surface the scenario

**Files:** Modify `library/src/components/RunTable.tsx`

- [ ] Add a compact `scenario` under the condition cell (mirror the `cell-sub` treatment), or add a "Scenario" column to `COLS`. Keep it subtle (muted text), matching the existing run-table density. Type-check + commit.

---

## Phase 5 — Backfill + verify

### Task 9: backfill known overrides + verify the pipeline

- [ ] **Hand Diego SQL** to set the real overrides (Supabase SQL editor), or run via `annotate.py --set` locally:

```sql
-- Little run: roommate moved in mid-run -> 2 occupants (1-room double)
update annotations set occupancy = 2
  where run_key = 'legacy_little_window_1_person_20260610T174830';

-- Fahey: within-run window experiment (open -> closed -> open)
insert into annotations (run_key, "window", updated_by)
  values ('legacy_1RSingle_-_Fahey_20260601T213527', 'open→closed→open', 'diego')
  on conflict (run_key) do update set "window" = excluded."window";
```

- [ ] **Run the pipeline locally** (reads `SUPABASE_DB_URL` from `library/.dev.vars`):

```bash
cd site/scripts && SUPABASE_DB_URL="$(grep '^SUPABASE_DB_URL=' ../../library/.dev.vars | cut -d= -f2-)" python build_catalog.py
grep -o '"scenario":[^,]*' ../../library/public/data/catalog.json | head
```

Expected: `little_window_1_person` shows `occupancy 2` + `scenario "window open · fan off"`; Fahey shows the window sequence.

- [ ] **Build the catalog app** + eyeball: `cd library && npm run build && npm run test`. Optionally `npx wrangler pages dev dist` and check a run's detail page renders Scenario/Window/Fan with the "(noted)" marker on overridden fields.

- [ ] **Final commit / PR.** The hourly cron (`:17`) deploys `main`; or trigger the `data-library` workflow.

---

## Self-review checklist
- Occupancy parsing already done (`94346e7`) — Phase 1 only adds window/fan/scenario.
- `window` (label-derived) is kept distinct from `window_state` (logged sensor) — both surface in RunDetail.
- Overrides are blank-safe: an empty override never wipes a label value.
- Reserved word: `window` is a column name — quote it (`"window"`) in SQL.
- No em-dashes in any added copy; scenario uses the middot `·` (DESIGN.md §2).
- Annotation values are set via SQL / CLI / Table Editor (the `/curate` web write is plan-gated and out of scope).

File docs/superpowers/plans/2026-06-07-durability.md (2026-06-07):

# Durability & Device Hardening Implementation Plan

> **For agentic workers:** REQUIRED SUB-SKILL: superpowers:subagent-driven-development or superpowers:executing-plans. Steps use `- [ ]` checkboxes. Written for a COLD START.
>
> **🔧 HARDWARE-GATED legend:** tasks marked **🔧 HARDWARE-GATED** change the ESP32 firmware and **cannot be fully verified by a cold session** — they need the physical device flashed over USB and observed. A cold agent should implement the code and run the build (`pio run`), then STOP at the verification step and hand off to Diego/cofounder for the on-device check. Tasks without the marker (the server `/api/ingest` endpoint) are fully cold-executable and TDD'd.

**Goal:** Harden the data path and the device so the dataset is durable and the device is safe to expose: (A) an authenticated server ingestion endpoint so the device can write readings straight to the SoR (removing the Google Sheet row ceiling), and (B) firmware hardening — endpoint auth, Anthropic-key protection, and the dashboard-refresh heap crash.

**Architecture:** Track A adds `POST /api/ingest` (Vercel function, mirrors the consent function: server-side `pg`, token-authenticated) that inserts reading batches into Supabase `readings`. Track B (firmware) adds a shared-secret check to the device's mutating endpoints, switches the device to **dual-write** (Sheet as today + the new `/api/ingest`) during transition, gets `/insight` behind auth, and addresses the heap crash. The Sheet stays as the cofounder's control surface; only the data path gains a direct, scalable route.

**Tech Stack:** Vercel function (Node `pg`) + vitest (Track A); ESP32 / Arduino / PlatformIO C++ (Track B); Supabase Postgres.

**Cold-start orientation — read first:**
- `site/api/consent.ts` + `site/api/_validate.ts` — the EXACT pattern Track A copies (Vercel function, `import pg from "pg"`, `ssl:{rejectUnauthorized:false}`, `./x.js` ESM import extension, server-side cred). **These gotchas already bit us once — replicate them, do not rediscover them.**
- `site/vercel.json` — the `/((?!api/).*)` rewrite already excludes `/api`; new functions need no change.
- `firmware/src/main.cpp` — the AsyncWebServer setup (`setupServer()` ~line 1463), the endpoints (`/data` GET, `/log/start|stop` GET, `/outdoor` POST, `/control` POST, `/insight` POST/GET), `logToSheets()` (~line 191, the current ingestion via `SHEETS_URL`), and the `/insight` Anthropic call (~line 457-508, uses `ANTHROPIC_API_KEY`).
- `firmware/include/config.h` + `firmware/include/secrets.h` — where `SHEETS_URL`, `ANTHROPIC_API_KEY`, Wi-Fi creds live (secrets.h is gitignored). New device secrets go here.
- `firmware/platformio.ini` — build env (`esp32dev`). Build with `pio run -e esp32dev`; flash with `pio run -e esp32dev -t upload`.

**Decisions confirmed:**
- Device ingestion is **dual-write** (Sheet + `/api/ingest`) initially — no big-bang cutover. Pruning the Sheet path comes later, after the direct path is proven on hardware.
- Endpoint auth = a **shared secret** (`X-Ventis-Token` header / `?token=`), stored in `secrets.h` on device and as a Vercel/CI env var server-side. Not per-user auth (that's the deferred "B" architecture).
- The Anthropic key stays in gitignored `secrets.h`; the fix is to (1) rotate it and (2) put `/insight` behind the shared-secret check so a softAP visitor can't burn credits.

---

## Prerequisites (Diego — manual)

- [ ] **🔴 Rotate the Anthropic API key now** (P0) in the Anthropic console; put the new value in `firmware/include/secrets.h` (`ANTHROPIC_API_KEY`). The old key was exposed via the unauthenticated `/insight`.
- [ ] Choose a device shared secret; set `VENTIS_INGEST_TOKEN` in the **Vercel** env (Track A) and the SAME value as `DEVICE_TOKEN` in `firmware/include/secrets.h` (Track B).
- [ ] Firmware tasks need the device on USB to flash + verify.

---

# Track A — Server ingestion endpoint (cold-executable, TDD)

## Task A1: Ingestion payload validator (pure, TDD)

**Files:**
- Create: `site/api/_ingest_validate.ts`
- Test: `site/api/_ingest_validate.test.ts`

- [ ] **Step 1: Write the failing tests**

`site/api/_ingest_validate.test.ts`:

```typescript
import { describe, it, expect } from "vitest";
import { validateIngest } from "./_ingest_validate";

const reading = {
  device_id: "ventis-01", run_id: "ventis-01_1717000000", condition: "fahey_window_1person",
  timestamp: "2026-06-01 21:00:00", co2_ppm: 812, temp_c: 22.1, humidity_pct: 44,
  fan_duty: 0, window_state: "open", consent: "anon",
};

describe("validateIngest", () => {
  it("accepts a batch of readings", () => {
    const r = validateIngest({ readings: [reading, reading] });
    expect(r.ok).toBe(true);
    if (r.ok) expect(r.value.length).toBe(2);
  });
  it("rejects a missing/empty batch", () => {
    expect(validateIngest({}).ok).toBe(false);
    expect(validateIngest({ readings: [] }).ok).toBe(false);
  });
  it("rejects a non-array readings field", () => {
    expect(validateIngest({ readings: "nope" }).ok).toBe(false);
  });
  it("caps batch size", () => {
    const big = { readings: Array(2000).fill(reading) };
    const r = validateIngest(big);
    expect(r.ok).toBe(false);   // over the per-request cap (e.g. 1000)
  });
  it("coerces numerics and drops rows with no timestamp", () => {
    const r = validateIngest({ readings: [{ ...reading, timestamp: "" }, reading] });
    expect(r.ok).toBe(true);
    if (r.ok) expect(r.value.length).toBe(1);   // the empty-timestamp row is dropped
  });
});
```

- [ ] **Step 2: Run to verify fail**

Run: `cd site && npx vitest run api/_ingest_validate.test.ts` → FAIL (module missing).

- [ ] **Step 3: Implement**

`site/api/_ingest_validate.ts`:

```typescript
export interface Reading {
  device_id: string; run_id: string; condition: string; timestamp: string;
  co2_ppm: number | null; temp_c: number | null; humidity_pct: number | null;
  fan_duty: number | null; window_state: string; consent: string;
}
type Result = { ok: true; value: Reading[] } | { ok: false; error: string };

const MAX_BATCH = 1000;
const num = (v: unknown): number | null => {
  const n = typeof v === "number" ? v : parseFloat(String(v));
  return Number.isFinite(n) ? n : null;
};
const str = (v: unknown, n: number) => String(v ?? "").slice(0, n);

export function validateIngest(body: any): Result {
  if (!body || typeof body !== "object") return { ok: false, error: "bad request" };
  const raw = body.readings;
  if (!Array.isArray(raw) || raw.length === 0) return { ok: false, error: "no readings" };
  if (raw.length > MAX_BATCH) return { ok: false, error: "batch too large" };
  const value: Reading[] = [];
  for (const r of raw) {
    const ts = str(r?.timestamp, 25).trim();
    if (!ts) continue;                       // Postgres timestamptz rejects ""
    value.push({
      device_id: str(r.device_id, 40), run_id: str(r.run_id, 60),
      condition: str(r.condition, 120), timestamp: ts,
      co2_ppm: num(r.co2_ppm), temp_c: num(r.temp_c), humidity_pct: num(r.humidity_pct),
      fan_duty: num(r.fan_duty), window_state: str(r.window_state, 16), consent: str(r.consent, 16),
    });
  }
  if (value.length === 0) return { ok: false, error: "no valid readings" };
  return { ok: true, value };
}
```

- [ ] **Step 4: Run to verify pass**

Run: `cd site && npx vitest run api/_ingest_validate.test.ts` → PASS (5).

- [ ] **Step 5: Commit**

```bash
git add site/api/_ingest_validate.ts site/api/_ingest_validate.test.ts
git commit -m "feat(ingest): reading-batch validator (TDD)"
```

## Task A2: The ingestion function

**Files:**
- Create: `site/api/ingest.ts`

- [ ] **Step 1: Implement (copy consent.ts's proven shape exactly)**

`site/api/ingest.ts`:

```typescript
import type { VercelRequest, VercelResponse } from "@vercel/node";
import pg from "pg";                                  // default import (ESM)
import { validateIngest } from "./_ingest_validate.js";  // .js extension (ESM)

const { Client } = pg;

export default async function handler(req: VercelRequest, res: VercelResponse) {
  if (req.method !== "POST") return res.status(405).json({ error: "method not allowed" });

  const token = req.headers["x-ventis-token"];
  if (!process.env.VENTIS_INGEST_TOKEN || token !== process.env.VENTIS_INGEST_TOKEN) {
    return res.status(401).json({ error: "unauthorized" });
  }

  const v = validateIngest(req.body);
  if (!v.ok) return res.status(400).json({ error: v.error });

  const url = process.env.SUPABASE_DB_URL;
  if (!url) return res.status(500).json({ error: "not configured" });

  const client = new Client({ connectionString: url, ssl: { rejectUnauthorized: false }, connectionTimeoutMillis: 8000 });
  try {
    await client.connect();
    const text =
      "insert into readings (timestamp,device_id,run_id,condition,co2_ppm,temp_c," +
      "humidity_pct,fan_duty,window_state,consent) values " +
      "($1,$2,$3,$4,$5,$6,$7,$8,$9,$10) on conflict (device_id, timestamp) do nothing";
    for (const r of v.value) {
      await client.query(text, [r.timestamp, r.device_id, r.run_id, r.condition, r.co2_ppm,
        r.temp_c, r.humidity_pct, r.fan_duty, r.window_state, r.consent]);
    }
    return res.status(200).json({ ok: true, inserted: v.value.length });
  } catch (e) {
    console.error("ingest failed:", e);
    return res.status(500).json({ error: "could not ingest" });
  } finally {
    await client.end().catch(() => {});
  }
}
```

- [ ] **Step 2: Build typechecks**

Run: `cd site && npm run build` → PASS.

- [ ] **Step 3: Commit**

```bash
git add site/api/ingest.ts
git commit -m "feat(ingest): token-authed /api/ingest writes readings to Supabase"
```

- [ ] **Step 4: e2e (needs VENTIS_INGEST_TOKEN + SUPABASE_DB_URL in Vercel, redeploy)**

```bash
# unauth -> 401
curl -s -o /dev/null -w "%{http_code}\n" -X POST https://ventis.vercel.app/api/ingest -H "Content-Type: application/json" -d '{"readings":[]}'
# authed test row -> 200 {"ok":true,"inserted":1}; then delete it from readings
curl -s -X POST https://ventis.vercel.app/api/ingest -H "Content-Type: application/json" \
  -H "X-Ventis-Token: <token>" \
  -d '{"readings":[{"device_id":"ingest-test","timestamp":"2026-06-07 12:00:00","co2_ppm":500}]}'
```
Confirm 401 without token, 200 with. Delete the `ingest-test` rows after.

---

# Track B — Firmware hardening (🔧 HARDWARE-GATED)

> Every task here requires flashing `firmware/` to the ESP32 and observing it. A cold agent: write the code, run `pio run -e esp32dev` to confirm it compiles, then STOP and hand the on-device verification to Diego/cofounder.

## Task B1: 🔧 HARDWARE-GATED — shared-secret auth on mutating endpoints

**Files:** Modify `firmware/src/main.cpp`, `firmware/include/secrets.h`

- [ ] **Step 1:** In `secrets.h` add `#define DEVICE_TOKEN "<same value as VENTIS_INGEST_TOKEN>"`.
- [ ] **Step 2:** In `main.cpp`, add a helper near `setupServer()`:

```cpp
static bool authed(AsyncWebServerRequest *req) {
  if (req->hasHeader("X-Ventis-Token"))
    return req->getHeader("X-Ventis-Token")->value() == DEVICE_TOKEN;
  if (req->hasParam("token"))
    return req->getParam("token")->value() == DEVICE_TOKEN;
  return false;
}
```

- [ ] **Step 3:** At the top of each mutating/sensitive handler (`/control` POST, `/log/start`, `/log/stop`, `/outdoor` POST, `/insight` POST), add:

```cpp
if (!authed(req)) { req->send(401, "application/json", "{\"error\":\"unauthorized\"}"); return; }
```

Leave read-only `/data` and the dashboard GET open (or gate them too if the dashboard passes the token). Update the dashboard's `fetch()` calls (the inline JS, e.g. `/control`, `/insight`) to send `headers:{'X-Ventis-Token': TOKEN}` where `TOKEN` is injected into the page from `DEVICE_TOKEN`.
- [ ] **Step 4:** `pio run -e esp32dev` compiles. **🔧 STOP — hand off:** flash + verify `/control` and `/insight` reject without the token and work with it.
- [ ] **Step 5:** Commit (`feat(fw): shared-secret auth on mutating + /insight endpoints`).

## Task B2: 🔧 HARDWARE-GATED — Anthropic key protection

- [ ] Confirm Task B1 gates `/insight` POST (the credit-burn vector). Confirm the rotated key is in `secrets.h` (Prerequisite). Confirm `ANTHROPIC_MODEL` is defined once (memory noted a double-#define between `main.cpp` and `secrets.h` — remove the duplicate). `pio run` compiles. **🔧 STOP — hand off:** verify `/insight` works with the token and is rejected without it. Commit.

## Task B3: 🔧 HARDWARE-GATED — dual-write readings to /api/ingest

**Files:** Modify `firmware/src/main.cpp`, `config.h`, `secrets.h`

- [ ] **Step 1:** Add `#define INGEST_URL "https://ventis.vercel.app/api/ingest"` to `config.h`.
- [ ] **Step 2:** Add a `postToIngest()` alongside `logToSheets()` that builds a JSON `{"readings":[{...one sample...}]}` from the same fields and POSTs to `INGEST_URL` with header `X-Ventis-Token: DEVICE_TOKEN` (mirror the `HTTPClient`/`WiFiClientSecure` usage in `logToSheets`). Call it wherever `logToSheets()` is called (dual-write). On non-200, log + continue (the Sheet remains the fallback).
- [ ] **Step 3:** `pio run -e esp32dev` compiles. **🔧 STOP — hand off:** flash, run a short logging session, confirm rows appear in Supabase `readings` (via `analyze.py` or the Supabase table) AND still in the Sheet.
- [ ] **Step 4:** Commit (`feat(fw): dual-write readings to /api/ingest (Sheet stays as fallback)`).

> Follow-up (separate, later): once dual-write is proven over multiple runs, retire the Sheet ingestion path and prune. Out of scope here.

## Task B4: 🔧 HARDWARE-GATED — dashboard-refresh heap crash

**Files:** Modify `firmware/src/main.cpp`

- [ ] **Step 1: Reproduce + instrument.** The WROOM restarts when the dashboard is refreshed (memory). Add `Serial.printf("[heap] free=%u minfree=%u\n", ESP.getFreeHeap(), ESP.getMinFreeHeap());` at the start of `/data`, `/history`, and `/insight` handlers. Flash, refresh the dashboard repeatedly, watch the heap fall. **🔧 device required.**
- [ ] **Step 2: Likely culprits (fix the one the heap trace implicates):**
  - Large `String` concatenations building JSON in handlers (`/history`, `/data`) fragment the heap → build responses with a fixed buffer / `AsyncResponseStream` instead of growing `String`s.
  - The in-RAM history buffer being copied per request → stream it, or cap its size.
  - `/insight` holding the Anthropic response in multiple `String`s → free promptly.
- [ ] **Step 3:** `pio run` compiles. **🔧 STOP — hand off:** flash, hammer-refresh the dashboard, confirm `minfree` stabilizes and no restart. Commit.

---

## Task A3 / B5: Open the PR

- [ ] `git push -u Ventis feat-durability` ; PR to `main`. Merge Track A after its e2e; Track B merges only after on-device verification by Diego/cofounder (mark those commits clearly so an unverified firmware change isn't merged blind).

## Self-review notes
- Track A is fully cold-executable and reuses the consent function's hard-won fixes (pg default-import, `.js` extension, SSL) — call those out so they aren't rediscovered.
- Every firmware task is explicitly **🔧 HARDWARE-GATED** with a STOP-and-hand-off step; a cold agent compiles but does not claim on-device success.
- Idempotent ingest (`on conflict (device_id,timestamp) do nothing`) means dual-write can't create duplicate readings vs the Sheet→CI path.
- Out of scope: retiring the Sheet path (after dual-write proven), per-user auth, the main.cpp refactor (monolith) beyond what these tasks touch.

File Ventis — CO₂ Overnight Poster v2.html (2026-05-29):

Ventis

Smart Dorm Ventilation

Thayer School of Engineering, Dartmouth

Dartmouth College · May 2026
Real sensor data · SCD40 CO₂ sensor

Ventis is not an air purifier or HEPA filter. It's a smart ventilation controller that reads your room's CO₂, temperature, and humidity — and runs your window fan automatically when outdoor conditions can help.

The air in your dorm room
while you sleep.

CO₂ overnight — Dartmouth dorm vs. off-campus apartment with central AC · windows closed · 1 occupant

⚠

CO₂ above 1,000 ppm impairs decision-making by up to 15%. Above 2,500 ppm, nearly 50%. The dorm trace below spent 4+ hours past that first threshold — every night, every student, invisible.

Satish et al., Environmental Health Perspectives, 2012 · Lawrence Berkeley National Laboratory

Dartmouth dorm — Little Hall (Choates), no AC · 1 person sleeping

CO₂ rose from 494 ppm at midnight to 1,111 ppm peak, spending 4+ hours above ASHRAE 1,000 ppm threshold.

Off-campus apartment — central AC · 1 person sleeping

CO₂ rose from 629 ppm to a 863 ppm peak — never crossed the 1,000 ppm threshold.

Filtration ≠ ventilation. In a separate overnight run, an air purifier ran all night in a similar dorm — CO₂ still reached 1,177 ppm. Only fresh-air exchange moves the needle.

Dorm peak

1,111 ppm

4+ hrs above ASHRAE threshold

Apartment peak

863 ppm

stayed below threshold all night

ASHRAE threshold

1,000 ppm

cognitive effects measurable here

Outdoor air

~405 ppm

baseline, Lebanon, NH

→ Visit our booth for a live demo + AI insightpress "Generate AI Insight" on the dashboard

Diego Turrubiartes & Emmanuel Uyigue · Thayer School of Engineering, Dartmouth '28
Diego.A.Turrubiartes.28@dartmouth.edu · Emmanuel.O.Uyigue.28@dartmouth.edu

Data: May 2026 · SCD40 sensor (±40 ppm) · 30s intervals · Little Hall (Choates) + Summit on Juniper, Lebanon, NH
ASHRAE Std. 62.1 · Satish et al. 2012 (Berkeley) · github.com/dturru/Ventis · MIT License

Dashboard QR code

Live air →
192.168.4.1

Survey QR code

30-sec
survey →

GitHub QR code

github.com/
dturru/Ventis

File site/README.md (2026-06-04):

# Ventis — Landing Site

Public marketing + data site for Ventis. React + Vite + TypeScript + React Router,
Recharts for the data charts. Built from `docs/superpowers/specs/2026-06-03-ventis-landing-site-design.md` (v1, ship-fast).

Lives in `site/` alongside the device dashboard in `app/`. Reuses the dashboard's
design tokens and the Dodi sprite.

## Develop

```bash
cd site
npm install
npm run dev      # http://localhost:5173
```

## Build

```bash
npm run build    # tsc type-check + vite build -> dist/
npm run preview  # serve the production build locally
```

## The data

`/data` renders four real measured overnight runs. The chart series live in
`src/data/runs.json`, generated from the source CSVs by:

```bash
npm run extract-data   # python scripts/extract_runs.py
```

Sources (real measured data — never fabricate values):
- **Fahey** (hero, window experiment) — `Ventis.v1 Logger - telemetry.csv`
- **East Wheelock** (negative control) — `Ventis.v1 Logger - 1RDouble - EW.csv`
- **Choates/Little** + **2-person apt** — vault `…/Ventis/Data/ventis_data.csv`

Lines are 5-minute averages; `peakLabel` carries the documented absolute single-sample peak.

## Config — swap before/after launch

Edit `src/site.config.ts`:
- `BETA_FORM_URL` — the live "Ventis — Early Access" Google Form URL (Residents CTA).
- `CONTACT_EMAIL` — Diego's Dartmouth email (mailto fallback + footer).
- `WEB3FORMS_KEY` — free access key for the `/contact` form. Empty for now → the
  form falls back to composing a pre-filled email in the visitor's mail app. To get
  real async delivery (submissions land in your inbox, no mail-client popup):
  grab a free key at https://web3forms.com (enter your email → they email you a key),
  paste it here, rebuild. No account/backend needed.

The Institutions CTA points to the `/contact` page (name / email / message form),
not a raw mailto.

## Deploy (Vercel)

1. Import the Ventis repo in Vercel.
2. **Set Root Directory = `site`.**
3. Framework preset: Vite. Build `npm run build`, output `dist`.
4. `vercel.json` already handles SPA route rewrites (so `/data` etc. deep-link).

Free subdomain (e.g. `ventis.vercel.app`) now; custom domain is a later 10-min add.

## Roadmap (not in v1)

- `/demo` is a placeholder. Phase 2 = embed the `app/` dashboard on a canned replay.
- Live "hosted dashboard": add `fetchLiveRun()` in `src/data/runs.ts` reading a
  Sheets-backed JSON endpoint. The page/chart don't change — only the data source.

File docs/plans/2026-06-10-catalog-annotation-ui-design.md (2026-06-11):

# Catalog Annotation UI — Design

**Date:** 2026-06-10
**Status:** Approved (brainstorm), pending implementation plan
**Goal:** Set run annotations (note + quality flag + tags) from any browser, behind the existing founders gate, instead of the `annotate.py` CLI on Diego's machine.

## Problem

Run annotations — the qualitative `note` + `quality_flag` (`good`/`caution`/`exclude`) + `tags` layer on top of the measured data — can currently only be set two ways:

1. `python annotate.py --set <run_key> --note … --flag …` on Diego's machine, or
2. Raw SQL / Table Editor in the Supabase dashboard.

Both require Diego specifically. Consent, by contrast, is already fully self-serve off-machine (occupant QR → `/consent` web form → `api/consent.ts` inserts to Supabase `consent_submissions` → `reconcile_consent.py` upserts to `consent` in CI). Annotations are the remaining "tacky command" gap.

This is **not** a consent problem — consent for new runs is solved. Scope is annotations only.

## Decision: annotation UI lives in the catalog

The UI and its write endpoint live in `library/` (the gated catalog on Cloudflare Pages), **not** on the Vercel marketing site.

Rationale:
- The catalog is already behind **Cloudflare Access (founders allowlist)** → zero new auth to build or secure. The marketing site is public and would need a new gate.
- Annotations are displayed in the catalog; the editor belongs on the same surface.
- `build_catalog` already reads the `annotations` table — the read side is done.

## Architecture

```
library/  (Cloudflare Pages, Access-gated)
  src/pages/Curate.tsx        founder UI — run worklist + flag/note/tags form
  functions/api/annotate.ts   Pages Function — upsert into Supabase `annotations`
```

**Flow:** Founder opens `…pages.dev/curate` (behind Access) → picks a run → sets flag + note + tags → `POST /api/annotate` → upsert into Supabase `annotations` → `build_catalog` reads it on the next hourly cron → flag appears in the catalog. Same instant-write / shows-next-build cadence as consent.

**Auth = the existing Access gate.** Cloudflare Access blocks every non-founder at the edge before the function runs. The function reads the `Cf-Access-Authenticated-User-Email` request header and stamps `updated_by` automatically (no manual `--by`).

## Key technical constraint (why this is not a copy of consent.ts)

`api/consent.ts` runs on **Vercel/Node** with the `pg` driver. Cloudflare Pages Functions run on the **Workers runtime**, where:

- `pg` (raw Node TCP) does not run, and
- the Supabase **Data API (PostgREST) is intentionally OFF** — the moat — so the REST API is not an option.

The function must therefore reach Supabase the same way the Python scripts do: a **direct Postgres connection to the Session-pooler**, but from the Workers runtime. Plan: **`postgres.js` (postgres v3) over Cloudflare's socket API**, running the identical `insert … on conflict (run_key) do update` that `annotate.py::_upsert_pg` performs. The moat is preserved (direct DB connection, not REST); only the driver differs from `pg`.

**Risk / first step:** verify a `postgres.js`-on-Workers connection to the Supabase Session-pooler with a tiny spike before building the page on top of it. Fallback if flaky: host the endpoint on Vercel and forward the Cloudflare Access JWT for verification. Not expected to be needed.

## Page UX

- The catalog already ships the run list (run_key, condition, existing flag/note/tags) as static build data — the Curate page reads that. **No new read endpoint.**
- Runs shown as a worklist with **unannotated runs surfaced first**; re-editing a run pre-fills existing values.
- Success state: "Saved — appears in the catalog within the hour."
- Client + server validation mirrors `_validate.ts`: `run_key` must exist; `quality_flag` ∈ {`good`, `caution`, `exclude`}; note/tags length-bounded.

## Data model

No schema change. Reuses the existing `annotations` table (`run_key`, `note`, `quality_flag`, `tags`, `updated_by`, `updated_at`) that `annotate.py` and `build_catalog` already use.

## Testing

- Unit-test the payload validator (valid/invalid flag, missing run_key, oversize fields), mirroring `_validate.test.ts`.
- Unit-test the upsert SQL shape / parameter binding, mirroring `test_consent_ledger`.
- Manual: set a flag via `/curate`, confirm the row in Supabase, confirm it renders after a `build_catalog` run.

## Out of scope

- **New-run consent** — already self-serve (QR → form → CI).
- **6 legacy PENDING consent rows** — a separate one-time browser cleanup via Supabase Table Editor straight into the `consent` table (they predate the web form and have no deployment code to reconcile). Steps handed off separately.
- **In-catalog editing of anything other than annotations.**

## Compatibility

`annotate.py` stays as-is — the CLI and the web UI write to the same table via the same upsert semantics, so they coexist. Nothing about the existing CLI / CI path changes.

## Deployment notes (one-time, Diego)

Code is built, unit-tested, and committed on `Ventis/feat-annotation-ui`. The remaining steps need the Supabase secret + dashboard access, so they're Diego's:

1. **Local end-to-end (verifies the postgres.js-on-Workers path):**
   - Paste the Session-pooler URI into `library/.dev.vars` (gitignored) — replace the `__PASTE_SESSION_POOLER_URI_HERE__` placeholder.
   - `cd library && npm run build && npx wrangler pages dev dist`
   - Open `/curate`, set a flag on a real run, Save → expect "Saved…". Confirm the row in Supabase Table Editor → `annotations`.
   - (Optional) `python site/scripts/build_catalog.py` then check the flag appears in `library/public/data/catalog.json`. Revert the test flag after.
2. **Cloudflare Pages → ventis-data-library → Settings → Environment variables:** add `SUPABASE_DB_URL` (Session-pooler URI) for Production **and** Preview.
3. **Settings → Functions → Compatibility flags:** add `nodejs_compat` for Production and Preview (also set in `library/wrangler.toml`; the dashboard setting is belt-and-suspenders).
4. **Cloudflare Access:** confirm the Founders access application covers the whole `ventis-data-library.pages.dev` host (default), so `/api/annotate` is gated — hit `/api/annotate` from a non-allowlisted browser and expect the Access wall, not a 200.
5. **Verify in production:** after deploy, open `/curate`, set a flag, confirm the Supabase row, confirm it renders after the hourly build.

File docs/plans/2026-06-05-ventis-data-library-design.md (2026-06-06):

# Ventis Data Library — Design (v1)

**Date:** 2026-06-05
**Status:** Approved design (pre-implementation)
**Author:** Diego + Claude (brainstorm)

## Problem / vision
A continuously-updating, professional "data library" where every Ventis logging run is easy to sort through and view (data + SOP charts). It is the moat-dataset made browsable — and a credibility asset for the upcoming Dartmouth/College engagement. Must be private, reachable by both founders (Diego remote, cofounder on campus), and auto-populating.

## Decisions (from brainstorm)
| Question | Decision |
|---|---|
| Audience / access | **Internal, both founders, hosted + private** (login-gated) |
| Core capability | **Catalog & browse** — sortable/filterable run table → run detail |
| Data flow | **Automatic / scheduled** refresh |
| Direction | **Approach A (scheduled static + gated host), built B-ready** — graduate to Supabase/Postgres (Approach B) when the relationship justifies per-user logins / scale |
| Feature scope | Read-only features fit A; write/auth features → B (see Scope) |

### Why A-now / B-later
For a *first* College meeting you show data, not logins — a polished gated catalog (A) is sufficient and identical in the room. B's real value (per-user College access, governance, multi-building scale) lands at the *pilot* phase. A doesn't waste work: the pipeline, schema, SQLite (Postgres-shaped), and charts all port into B; only A's static frontend is replaced. A keeps the moat key **ephemeral** (CI-only) vs B's always-on key-holder.

## Architecture
```
ESP32 → Apps Script → Google Sheet (telemetry, ingest buffer)
                          │  read-only service-account key (CI secret, ephemeral)
        GitHub Action (cron, ~hourly)   ← the "scheduled backend", ephemeral
                          │
   sheet_source → sqlite_sync (ventis.db) → archive_runs (per-run CSV + manifest)
       → plot_ventis_run (SOP charts) → build_catalog.py
                          │  (catalog.json + per-run series JSON + chart PNGs)
        build static React/Vite catalog app → deploy
                          │
        Private host (Cloudflare Pages + Access, or Vercel Auth) — gate = both founders
                          │
   log in → sort/filter run table → click run → SOP chart + stats + context + notes
```
Nothing always-on holds the key; the deployed artifact is a static app + JSON + PNGs behind an edge access-gate.

## Components
1. **Pipeline (exists):** `sheet_source` → `sqlite_sync` → `archive_runs` → `plot_ventis_run` → `refresh_backup`. The Action invokes these.
2. **`build_catalog.py` (new):** reads `ventis.db` → emits:
   - `catalog.json` — one record per run (the B-ready contract, below).
   - `series/<run_id>.json` — **downsampled** per-run time-series (CO₂/temp/RH). Emitted in v1 so the **comparison** view (v1.1) is data-ready with no rework.
   - copies chart PNGs into the app's asset dir.
3. **Catalog frontend (new):** React/Vite app reusing existing site design tokens for a consistent professional look. Views:
   - **Run table** — sortable/filterable: building, condition, occupancy, window_state, date, duration, n_rows, co2_mean, co2_peak, ASHRAE-exceed, consent, run_id. Text search.
   - **Run detail** — SOP chart, full stats, context (window/door/occupancy/placement), analysis-note text.
4. **GitHub Action (new):** cron (~hourly) → run pipeline + `build_catalog.py` → deploy. SA key + deploy token = encrypted CI secrets.
5. **Host + auth:** Cloudflare Pages + Cloudflare Access (email allowlist for the two founders), or Vercel Authentication. Free tier.

## B-ready data contract (`catalog.json` record)
```
run_id, run_key, device_id, building, condition, occupancy, window_state,
date, start, end, duration_h, n_rows, co2_mean, co2_peak, ashrae_exceed,
consent, chart, csv, series, notes
```
This maps **1:1 to the future Postgres `runs` table**. `building` / `occupancy` parse from the `building_condition_occupancy` label (guaranteed by run_id + the structured-label rule). At graduation, the same frontend swaps its source from `catalog.json` → Supabase; schema + UI are unchanged.

## Security (moat-critical)
- Read-only SA key = encrypted **CI secret**, present only during the ~30s Action run.
- The deployed site **contains the dataset** (charts + catalog.json) → the **host access-gate is the privacy boundary.** Cloudflare Access / Vercel Auth gate at the edge *before any asset loads*.
- **Hard rule: never deploy ungated, not even once.** Verify the gate blocks anonymous requests before the first real deploy.
- Read-only catalog, no write/upload path → no injection surface.
- Moat data (db, CSVs, JSON, PNGs) are CI build artifacts, **never committed** (`library/` build output gitignored).

## Scope
**In (A v1):** catalog table + filter/sort + run detail; auto-refresh cron; private gate. `build_catalog.py` also emits per-run series JSON so comparison is data-ready.
**A v1.1 (first enhancement):** comparison / overlay view (read-only, client-side — architecturally free in A; the self-serve pitch-chart builder).
**Deferred to B (graduation):** annotations (needs persistent writes + auth), upload UI (needs writes; ingestion is already automatic), optional in-UI ad hoc query (CLI `sqlite_sync.py --sql` already covers this).

**Principle:** read-only features fit A (static); write/auth/state features require B. Bolting a write-backend onto A = half-building B → just graduate instead.

## Verification
- `build_catalog.py`: valid `catalog.json` shape; every referenced chart + series file exists; building/occupancy parsed correctly from labels.
- Frontend: renders from a sample `catalog.json`; filter/sort works; run detail loads chart + series.
- **Gate:** an unauthenticated request is blocked (test before first real deploy).
- Action: dry-runs clean on a branch before enabling the cron.

## Graduation path to B (Supabase)
Trigger: College wants a pilot / per-user logins / multi-building. Steps: stand up Supabase; load `ventis.db` → Postgres `runs` table (= `catalog.json` schema); point the same frontend at Supabase with auth + row-level security; issue read-only College accounts; add annotations + upload + optional UI query. Frontend + schema already match → low-friction.

## Open questions — RESOLVED (built + live 2026-06-05)
- ~~Host~~ → **Cloudflare Pages + Cloudflare Access** (gate over apex + `*.pages.dev` wildcard via Pages preview-protection; anon → 302 login, verified). Deploy via `wrangler-action`, production-only (`--branch=main`).
- ~~Cron cadence~~ → **hourly** (`17 * * * *`).
- ~~Design tokens~~ → **reused** the `app/` Ventis tokens (`library/src/theme.css`).

**Status: LIVE** at https://ventis-data-library.pages.dev (PR #2 merged to `main`; all 12 plan tasks done). Future: v1.1 compare view (series JSON already emitted), graduate to Supabase/Postgres (Approach B) when per-user logins / pilot justify it.

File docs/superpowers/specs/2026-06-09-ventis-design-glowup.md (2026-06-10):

# Ventis Design Glow-Up — Spec (2026-06-09)

Visual / brand pass on the two live front-ends. Code-only (Claude Code ships;
Claude Design assets are an optional later layer). No feature changes, no copy
rewrites, claim-integrity intact.

## Decisions (locked with Diego)

- **Scope:** both surfaces — the public site (`site/`) and the data library (`library/`).
- **Site direction:** "Dialed-up field report" — keep the editorial green system,
  add craft (warmer paper + subtle grain, one signature hero data-moment, pull-quote
  typography, finer micro-interactions). Refine, don't reinvent. The site is the
  outward-facing credibility asset (Conklin / ResOps / beta), so low risk.
- **Library:** full system port. It's a barely-touched Vite starter (orphaned
  `index.css`/`App.css` with a purple `--accent`, system font, inline-styled tables).
  Bring it onto the site's editorial system so it reads like a credible data *product*.
- **Council note:** the June 6 "stop polishing the catalog" ruling was about
  *features*. This is purely visual/brand, which supports the moat/acquisition story
  (a credible-looking dataset), so it's in-bounds.

## Phase A — Data library port

Files:
- `library/index.html` — add DM Serif Display / Outfit / DM Mono (mirror `site/index.html`),
  real `<title>` + description + theme-color, keep favicon.
- `library/src/theme.css` — rewrite into the full system: port the site's token set
  (greens, bone/mist neutrals, ink/muted/faint, line, shadow trio, serif/sans/mono,
  radii, maxw), atmospheric `body::before` backdrop, selection color. Keep the
  device-app aliases (`--fg`, `--border`, `--tile-alt`, `--green-light`, etc.) mapped
  to the new tokens so existing references stay valid. Add component classes
  (header, run-index, table, cards, chips, badges, stat tiles, prose).
- Delete orphaned `library/src/index.css` + `library/src/App.css` (dead Vite cruft).
- `library/src/components/Header.tsx` (new) — glassy fixed header: air-flow brand mark
  (mirror `site/.../Nav.tsx`) + "Ventis · Data Library" serif wordmark + nav
  (Runs / Compare / About / Operations). Footer with the private-catalog note.
- `library/src/App.tsx` — wrap routes in the Header/footer shell.
- `RunTable.tsx` — branded run index: refined table, CO₂-tier chips, mono numerals,
  ASHRAE / quality / consent badges. Remove the 🔍 emoji + em-dash placeholders.
- `RunDetail.tsx` — editorial run page; replace ⬇ emoji with an SVG; mono stat values.
- `ComparePage.tsx` — restyle controls + chart card; tune recharts to the palette.
- `StatsBar.tsx` — serif-numeral stat tiles (like the site `.point-k`).
- `AboutPage.tsx` / `OperationsPage.tsx` / `DeployPage.tsx` — restyle to match.

Unchanged: gated/private (Cloudflare Access), all catalog logic, `build_catalog`
output contract, the `Run` shape. Visual only.

## Phase B — Public site craft pass ("dialed-up field report")

- `site/src/global.css` — warmer paper (`--bone`/`--bg` tuned) + a subtle SVG grain
  overlay (gated behind reduced-motion-safe, low-opacity, fixed). Pull-quote class.
  Finer hover/lift micro-interactions on existing primitives.
- Signature hero data-moment on `site/src/pages/Home.tsx` — the 1,111 ppm reading
  rising against the ASHRAE 1,000 line (a small self-contained animated SVG/Recharts
  "live air ribbon" in the hero), reduced-motion safe, traces to real data.
- `site/DESIGN.md` — update to record the changes (the doc's own rule).
- Copy untouched. Re-run `grep -rn "—" site/src` before finishing (em-dash bar = 0).

## Verification

- `npm run build` green in both `site/` and `library/` (tsc + vite; library vitest stays green).
- Render-verify each changed route (desktop + ≤640px). Library is gated, so verify via `npm run dev` locally.
- Site pre-ship checklist (`DESIGN.md` §9): contrast, focus, reduced-motion,
  375/768/1024/1440, no emoji icons, claim integrity, no pricing.
- Branch `Ventis/feat-design-glowup`; commit atomically; **do not push** (auto-deploys) —
  Diego previews locally and merges.

## Out of scope (deferred)

- Claude Design assets (hero illustration, OG/social image) — drop in later, no rework.
- Any feature work on the catalog (council ruling).
- Copy/positioning rewrites (Claude Desktop's domain; handoff if needed).

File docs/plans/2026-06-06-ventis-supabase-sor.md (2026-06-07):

# Ventis Supabase System-of-Record Migration — Implementation Plan

> **For Claude:** REQUIRED SUB-SKILL: Use superpowers:executing-plans to implement this plan task-by-task.

**Goal:** Make Supabase Postgres the durable, always-on, off-laptop system-of-record holding the FULL union of Ventis readings (live Sheet + archived per-run CSVs + pre-Sheet historical), synced hourly by CI. Removes the "dataset lives on one laptop" risk, gives the cofounder SQL access, and survives Sheet pruning.

**Rationale:** Council verdict 2026-06-06 (vault `Council Verdict — Acquisition Roadmap Sequencing 2026-06-06`) — durability is the load-bearing, solo-doable move; the at-risk data is the archived/historical runs that (post-prune) live only on Diego's disk. This is Tier 2 of the storage spec (`Data Storage — run_id + Archival + Scaling Spec`).

**Scope (this cut):** Stand up the schema + an idempotent `supabase_sync.py` that upserts the union into Postgres, run it in CI hourly. KEEP the existing catalog build (reads the CI-rebuilt SQLite) unchanged — Supabase is the durable SoR + cofounder access now; pointing `build_catalog` at Supabase is a **later** step (noted at the end). YAGNI: no firmware change (device still POSTs to the Sheet), no per-user app auth (Supabase dashboard access covers the two founders).
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

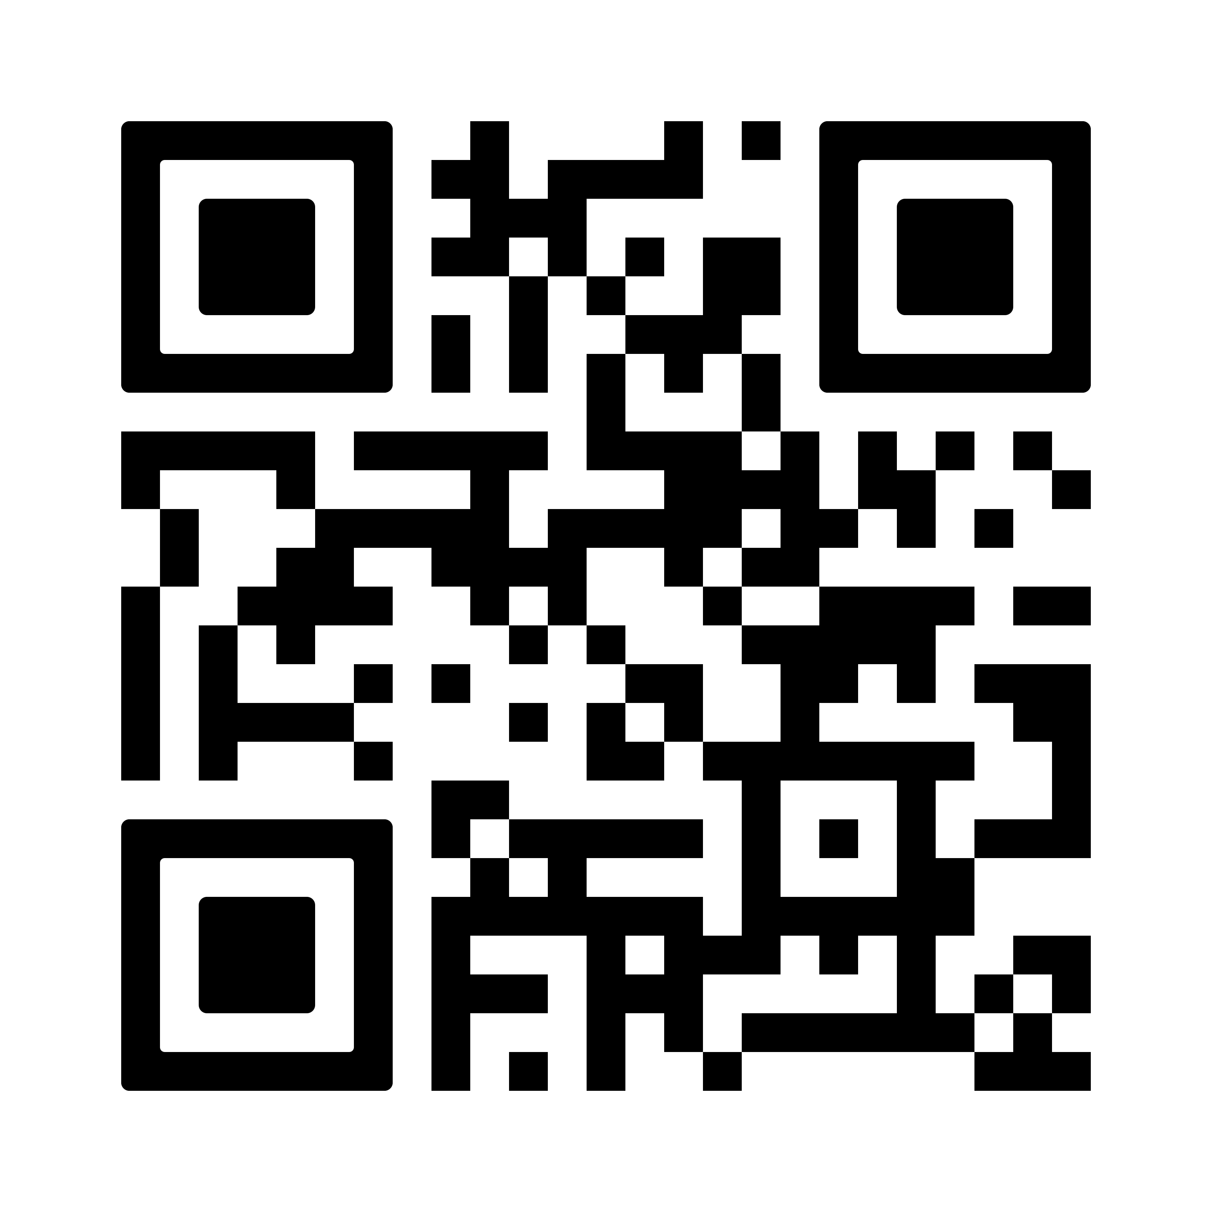
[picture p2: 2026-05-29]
ventis_github_QR (2).png

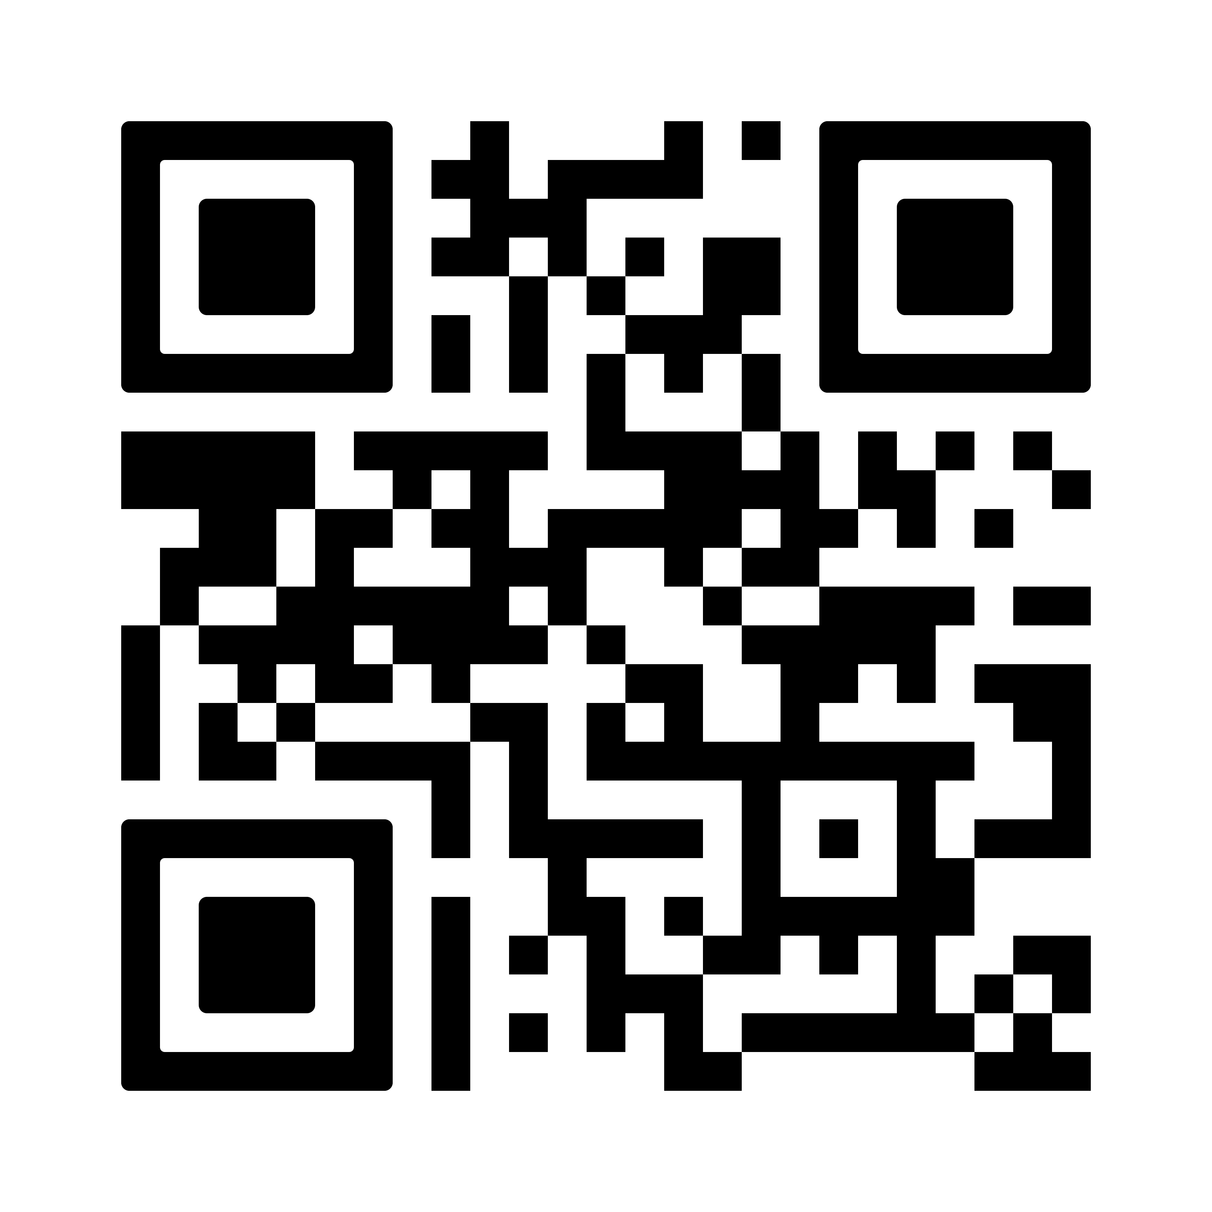
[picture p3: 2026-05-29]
Survey1_Ventisv1_QR.png

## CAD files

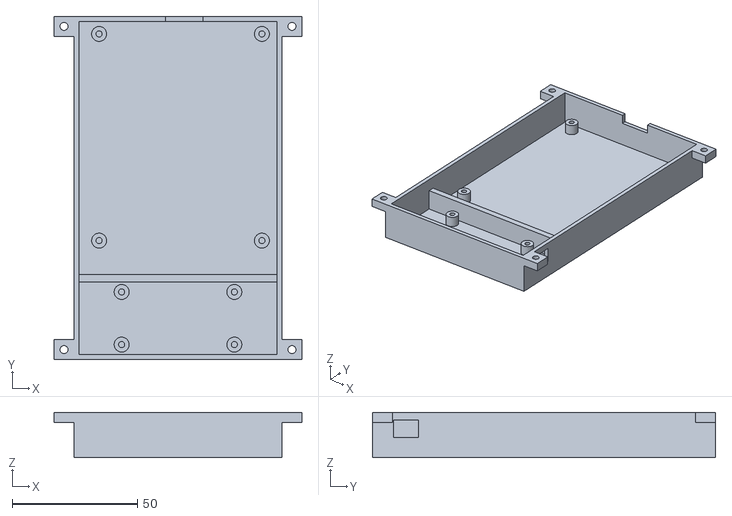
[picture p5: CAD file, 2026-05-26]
cad/v1 case - back half.stl
99.0 x 137.0 x 18.0

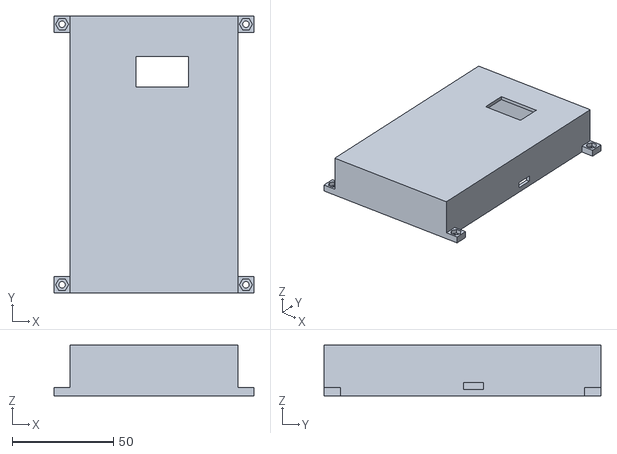
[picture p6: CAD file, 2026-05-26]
cad/v1 case - front half.stl
99.0 x 137.0 x 25.0

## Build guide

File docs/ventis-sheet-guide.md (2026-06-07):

# Ventis Logger — Quick Guide (paste into the Sheet's `guide` tab)

## Labeling rule (cardinal)
Every run's **condition** label is: `building_condition_occupancy`
- **all lowercase, no spaces** (use `_`)
- **NEVER a person's name or a room number** (anonymization — this is the rule that protects the dataset)

Examples: `little_baseline_1person` · `eastwheelock_fanclosed_2person` · `midmass_windowfan_3person`

- **building** = a slug from the list below
- **condition** = what's being tested: `baseline`, `window`, `windowfan`, `fanclosed`, `door_open`, ...
- **occupancy** = `1person`, `2person`, `3person` (count the people in the room)

## Building slugs (use these; add new ones lowercase, no spaces)
`fahey` · `judge` · `eastwheelock` · `little` · `midmass` · `summit` (off-campus)
`cohen` · `bissell` · `brown` · `french` · `mclane` · `hitchcock` · `zimmerman` · `wheeler` · `richardson` · `morton` · `mcculloch` · `russellsage` · `butterfield` · `streeter` · `lord` · `topliff` · `ripley` · `smith` · `woodward` · `gile` · `northmass` · `southfay` · `midfay` · `northfay` · `hinman` · `andres` · `maxwell`

> If your building isn't listed, add it as one lowercase word (no spaces). Keep it consistent across runs.

## Consent (BEFORE you start a run)
Get the occupant's opt-in first, and tell them it's anonymized + opt-out-able.

**Easiest way — the web form + QR:** open the **Deployment QR generator** on the catalog (`/deploy`), pick a `VEN-####` code, type the condition label → it gives you a QR + link. The occupant scans it and taps **I agree** (self-serve), or you open it on your phone and submit the **assisted** opt-in. The link is `ventis.vercel.app/consent?code=VEN-####&c=<condition_label>`.

> **The condition in the QR must EXACTLY match the condition you put in `B2` of the `control` tab** (same building_condition_occupancy string). That match is what links the opt-in to the run.

Methods recorded automatically: `opt_in_form` (occupant self-serve) / `opt_in_verbal` (assisted). For your own room or backfilling, the CLI still works:
`python site/scripts/consent_ledger.py --set <run_key> --method occupant_self --date <YYYY-MM-DD> --terms v1-2026-06 --by <you>`
Full SOP = the catalog **Operations** page.

## Start / stop a run (the `control` tab)
The `control` tab is a **single-row register — only ROW 2 matters.** Editing any other row does nothing.

1. `A2` = logging → `TRUE` to start, `FALSE` to stop
2. `B2` = the condition label (see above)
3. `C2` = `seq` → **bump it to a NEW, higher number every time** you change a command (the device only acts when `seq` increases; the value survives reflash)

If nothing happens: you probably edited the wrong row, or didn't bump `seq`.

## After a run
Run `/ventis-backup` (refreshes SQLite + archives + charts + backs up to OneDrive). Hand off to Diego.

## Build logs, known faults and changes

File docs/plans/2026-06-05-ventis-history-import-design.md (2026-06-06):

# Ventis Data Library — Historical Import, Robust Labeling & Cofounder Guide (Design)

**Date:** 2026-06-05
**Builds on:** `2026-06-05-ventis-data-library-design.md` (the live catalog). This adds the *rest* of the runs + fixes building extraction + a cofounder guide.

## Problem
The live catalog (https://ventis-data-library.pages.dev) shows only **Fahey + Judge** — the two runs in the live Sheet. Two issues:
1. **Building mislabeled:** `parse_label` takes the first token as building, so the legacy `1RSingle - Fahey` shows building `1rsingle` instead of `fahey`.
2. **Missing runs:** the other historical runs (East Wheelock, Summit/apt, Little, Mid-Mass "T window fan") live as gitignored legacy CSVs. The repo is **public** and `archive/` is gitignored (the moat), so CI rebuilds the catalog from the **Sheet only** → those runs never reach the live site.

## Decisions
- **Single source = the live Sheet.** Import the historical runs into the Sheet so CI (and local) naturally include them forever. (Chosen over a separate private CI source or local-only.)
- **Write method = script-emits-CSV, paste manually.** The read-only service-account key is never widened (matches the storage spec's "separate write path"). The import script produces a telemetry-schema CSV; Diego pastes it into the Sheet. Guide-tab text pasted likewise.
- **Fix labels in code, not by editing 2,548 existing rows.** `parse_label` becomes robust (known-building scan + occupancy variants), so legacy labels render correctly without rewriting Sheet history.

## Canonical labels (`building_condition_occupancy`)
| Run | Raw label | Canonical | Occ |
|---|---|---|---|
| Fahey (in Sheet) | `1RSingle - Fahey` | `fahey_window_1person` | 1 |
| Judge (in Sheet) | `Judge_3RDouble` | `judge_baseline_2person` | 2 |
| East Wheelock | `eastwheelock_fan_closed_2ppl` | `eastwheelock_fanclosed_2person` | 2 |
| Summit on Juniper (apt) | `apt_bedroom_two_ppl` | `summit_bedroom_2person` | 2 |
| Little Hall | `dorm_baseline_occupied` | `little_baseline_1person` | 1 |
| Mid Mass Hall (was "T") | `T window fan` | `midmass_windowfan_3person` | 3 (2-room triple) |

Fahey/Judge stay as-is in the Sheet; the robust `parse_label` resolves their building. The 4 imported runs land with clean canonical labels.

## Components
1. **Robust `parse_label`** (`site/scripts/build_catalog.py`)
   - `KNOWN_BUILDINGS` registry: our data buildings (`fahey, judge, eastwheelock, summit, little, midmass`) + confident Dartmouth halls; trivially extensible.
   - Building = first `KNOWN_BUILDINGS` token found anywhere in the label; else first token (back-compat).
   - Occupancy = `(\d+)person` | `(\d+)ppl` | word-numbers (`one..six`). `occupied`/blank → None (but our relabels carry explicit `Nperson`).
   - Unit tests for: `1RSingle - Fahey`→fahey/1; `eastwheelock_fanclosed_2person`→eastwheelock/2; `midmass_windowfan_3person`→midmass/3; `summit_bedroom_2person`→summit/2; legacy fallback unchanged.

2. **`site/scripts/import_history.py`** (one-time, re-runnable)
   - Input: the 4 historical CSVs (from the OneDrive FULL-dataset backup / `archive/`).
   - Map legacy schema → telemetry schema (`run`→`condition`, `co2`→`co2_ppm`, `temp_in_c`→`temp_c`, `fan_on`→`fan_duty` 0/100, fill `humidity_pct`).
   - Relabel `condition` per the table; sanitize (anonymize: strip names/room numbers, force `device_id=ventis-01`, `consent=anon`).
   - Emit one telemetry-schema CSV (`archive/history_import.csv`) with the canonical `COLUMNS` order, ready to paste into the Sheet's `telemetry` tab.
   - Idempotent downstream: `sqlite_sync` dedups on `UNIQUE(device_id, timestamp)`, so a re-paste won't duplicate.

3. **`guide` tab content** (`docs/ventis-sheet-guide.md` → paste into a new Sheet tab)
   - Labeling convention `building_condition_occupancy` + examples.
   - The `KNOWN_BUILDINGS` slug list (consistent building names).
   - Start/stop steps + the control-tab **row-2 + bump `seq`** gotcha (from the Logger Deployment SOP).

## Data flow
historical CSVs → `import_history.py` (map + relabel + sanitize) → **paste into Sheet** → existing pipeline (`sqlite_sync` unions Sheet) → robust `build_catalog` → catalog.json → CI deploy → live catalog shows all 6 runs, correct buildings.

## Testing
- `parse_label` unit tests (above) — pytest.
- `import_history` test: a legacy-schema fixture row maps to the right telemetry columns + canonical label + sanitized device id.
- Verification: after paste + `sqlite_sync`, `runs` table has 6 rows with the canonical conditions; `build_catalog` → catalog.json has 6 records with correct `building`/`occupancy`; manual `workflow_dispatch` → live site shows all 6.

## Out of scope (YAGNI)
- No automated Sheet writes (manual paste). No editing existing Fahey/Judge rows. No exhaustive every-hall list now (seed + extend). Compare view still v1.1.

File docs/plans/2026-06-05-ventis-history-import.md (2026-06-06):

# Ventis Historical Import + Robust Labeling Implementation Plan

> **For Claude:** REQUIRED SUB-SKILL: Use superpowers:executing-plans to implement this plan task-by-task.

**Goal:** Get all 6 Ventis runs onto the live catalog with correct building names, by making `parse_label` robust and importing the 4 historical runs into the Sheet via a paste-able CSV.

**Architecture:** (1) Upgrade `parse_label` in `build_catalog.py` to scan a `KNOWN_BUILDINGS` registry + recognize occupancy variants. (2) A one-time `import_history.py` maps the legacy CSVs → telemetry schema, relabels to canonical `building_condition_occupancy`, sanitizes, and emits `archive/history_import.csv` for manual paste into the Sheet. (3) A paste-able cofounder guide. Then the existing pipeline + CI surface everything.

**Tech Stack:** Python 3 stdlib + pytest. No new deps.

**Design doc:** `docs/plans/2026-06-05-ventis-history-import-design.md`

**Conventions:** paths relative to repo root. Moat data stays gitignored (`archive/`). Work on branch `feat-history-import`.

---

## Phase 1 — Robust `parse_label`

### Task 1: Known-building scan

**Files:**
- Modify: `site/scripts/build_catalog.py`
- Test: `site/scripts/tests/test_build_catalog.py`

**Step 1: Write the failing test** (append)
```python
def test_parse_label_known_building_anywhere():
    # legacy "roomtype - building" must still resolve the building
    assert parse_label("1RSingle - Fahey")["building"] == "fahey"
    # building-first convention still works
    assert parse_label("judge_baseline_2person")["building"] == "judge"
    assert parse_label("eastwheelock_fanclosed_2person")["building"] == "eastwheelock"
    # unknown building -> first-token fallback (back-compat)
    assert parse_label("mystery_x_1person")["building"] == "mystery"
```

**Step 2: Run to verify it fails**
`python -m pytest site/scripts/tests/test_build_catalog.py::test_parse_label_known_building_anywhere -v` → FAIL.

**Step 3: Minimal implementation** — in `build_catalog.py`, add the registry above `parse_label` and use it:
```python
KNOWN_BUILDINGS = {
    # Ventis dataset buildings
    "fahey", "judge", "eastwheelock", "summit", "little", "midmass",
    # Dartmouth halls (seed; extend as runs are deployed)
    "cohen", "bissell", "brown", "french", "mclane", "hitchcock", "zimmerman",
    "wheeler", "richardson", "morton", "mcculloch", "russellsage", "butterfield",
    "streeter", "lord", "topliff", "ripley", "smith", "woodward", "gile",
    "northmass", "southfay", "midfay", "northfay", "hinman", "andres", "maxwell",
}

def parse_label(condition: str):
    """building_condition_occupancy -> {building, occupancy}. Tolerant of legacy.
    Building = first KNOWN_BUILDINGS token found anywhere, else first token."""
    s = str(condition or "").strip().lower()
    toks = [t for t in re.split(r"[^a-z0-9]+", s) if t]
    building = next((t for t in toks if t in KNOWN_BUILDINGS), toks[0] if toks else "")
    occ = _occupancy(toks)
    return {"building": building, "occupancy": occ}
```
(Leave the existing occupancy loop for now — Task 2 replaces it with `_occupancy`.)
For Task 1 only, keep occupancy inline if `_occupancy` not yet defined — simplest: define a stub `_occupancy` returning the existing logic:
```python
WORD_NUM = {"one":1,"two":2,"three":3,"four":4,"five":5,"six":6}

def _occupancy(toks):
    for t in toks:
        m = re.match(r"(\d+)person$", t)
        if m:
            return int(m.group(1))
    return None
```

**Step 4: Run to verify it passes** — PASS (and the 6 existing tests still pass: `... test_build_catalog.py -v`).

**Step 5: Commit**
```bash
git add site/scripts/build_catalog.py site/scripts/tests/test_build_catalog.py
git commit -m "feat(catalog): parse_label scans KNOWN_BUILDINGS (fixes legacy building)"
```

---

### Task 2: Occupancy variants

**Files:**
- Modify: `site/scripts/build_catalog.py` (`_occupancy`)
- Test: `site/scripts/tests/test_build_catalog.py`

**Step 1: Write the failing test** (append)
```python
def test_parse_label_occupancy_variants():
    assert parse_label("eastwheelock_fanclosed_2person")["occupancy"] == 2
    assert parse_label("eastwheelock_fan_closed_2ppl")["occupancy"] == 2
    assert parse_label("summit_bedroom_two_ppl")["occupancy"] == 2
    assert parse_label("midmass_windowfan_3person")["occupancy"] == 3
    assert parse_label("little_baseline_occupied")["occupancy"] is None
```

**Step 2: Run to verify it fails** — `2ppl` / `two_ppl` not handled → FAIL.

**Step 3: Minimal implementation** — replace `_occupancy`:
```python
WORD_NUM = {"one":1,"two":2,"three":3,"four":4,"five":5,"six":6}

def _occupancy(toks):
    # digit forms: "2person", "2ppl"
    for t in toks:
        m = re.match(r"(\d+)(person|ppl)$", t)
        if m:
            return int(m.group(1))
    # word forms: "two" immediately before "ppl"/"person"
    for i, t in enumerate(toks):
        if t in ("ppl", "person") and i > 0 and toks[i-1] in WORD_NUM:
            return WORD_NUM[toks[i-1]]
    return None
```

**Step 4: Run to verify it passes** — PASS (all prior tests too).

**Step 5: Commit**
```bash
git add site/scripts/build_catalog.py site/scripts/tests/test_build_catalog.py
git commit -m "feat(catalog): parse_label recognizes Nppl + word-number occupancy"
```

---

## Phase 2 — Historical import script

### Task 3: Legacy-row mapper (pure function)

**Files:**
- Create: `site/scripts/import_history.py`
- Test: `site/scripts/tests/test_import_history.py`

**Step 1: Write the failing test**
```python
import sys, os
sys.path.insert(0, os.path.dirname(os.path.dirname(os.path.abspath(__file__))))
from import_history import map_row, RELABEL

def test_map_row_legacy_schema():
    raw = {"timestamp": "2026-06-01 01:00:00", "run": "eastwheelock_fan_closed_2ppl",
           "co2": "812", "temp_in_c": "22.5", "humidity_pct": "44"}
    r = map_row(raw, "eastwheelock_fanclosed_2person")
    assert r["condition"] == "eastwheelock_fanclosed_2person"
    assert r["co2_ppm"] == "812"
    assert r["temp_c"] == "22.5"
    assert r["device_id"] == "ventis-01"
    assert r["consent"] == "anon"
    # canonical telemetry columns present
    for c in ("timestamp","device_id","condition","co2_ppm","temp_c","humidity_pct",
              "fan_duty","window_state","consent"):
        assert c in r

def test_map_row_fan_on_to_duty():
    raw = {"timestamp": "t", "run": "T window fan", "co2": "700",
           "temp_in_c": "21", "humidity_pct": "40", "fan_on": "true"}
    assert map_row(raw, "midmass_windowfan_3person")["fan_duty"] == 100
    raw["fan_on"] = "false"
    assert map_row(raw, "midmass_windowfan_3person")["fan_duty"] == 0
```

**Step 2: Run to verify it fails** — FAIL (`import_history` missing).

**Step 3: Minimal implementation** — `site/scripts/import_history.py`:
```python
"""One-time importer: legacy run CSVs -> telemetry-schema CSV for pasting into the Sheet.

Maps legacy columns -> telemetry schema, relabels condition to the canonical
building_condition_occupancy convention, and anonymizes (device_id=ventis-01,
consent=anon). Emits archive/history_import.csv. Read-only on the Sheet (we never
write to it from here) — Diego pastes the output. See design doc.

Usage:
  python import_history.py --csv "<file1>" "<file2>" ...   # explicit inputs
  python import_history.py                                  # default: archive/_history/*.csv
"""
import csv, glob, os, sys

HERE = os.path.dirname(os.path.abspath(__file__))
ARCHIVE_DIR = os.path.join(HERE, "archive")
OUT_CSV = os.path.join(ARCHIVE_DIR, "history_import.csv")

COLUMNS = ["timestamp", "device_id", "condition", "co2_ppm", "temp_c",
           "humidity_pct", "fan_duty", "window_state", "consent"]

# raw condition (as it appears in the legacy CSV) -> canonical label
RELABEL = {
    "eastwheelock_fan_closed_2ppl": "eastwheelock_fanclosed_2person",
    "T window fan":                 "midmass_windowfan_3person",
    "apt_bedroom_two_ppl":          "summit_bedroom_2person",
    "dorm_baseline_occupied":       "little_baseline_1person",
}

ALIASES = {"run": "condition", "co2": "co2_ppm", "temp_in_c": "temp_c"}

def _truthy(v):
    return str(v).strip().lower() in ("true", "1", "1.0", "yes", "on")

def map_row(raw: dict, canonical_label: str) -> dict:
    g = {ALIASES.get(k, k): v for k, v in raw.items()}
    fan = 100 if _truthy(g.get("fan_on", "")) else 0
    if "fan_duty" in g and str(g.get("fan_duty")).strip() not in ("", "None"):
        try: fan = int(float(g["fan_duty"]))
        except ValueError: pass
    return {
        "timestamp":   g.get("timestamp", ""),
        "device_id":   "ventis-01",
        "condition":   canonical_label,
        "co2_ppm":     g.get("co2_ppm", ""),
        "temp_c":      g.get("temp_c", ""),
        "humidity_pct":g.get("humidity_pct", ""),
        "fan_duty":    fan,
        "window_state":"",
        "consent":     "anon",
    }
```

**Step 4: Run to verify it passes** — PASS.

**Step 5: Commit**
```bash
git add site/scripts/import_history.py site/scripts/tests/test_import_history.py
git commit -m "feat(import): legacy-row -> telemetry-schema mapper + relabel"
```

---

### Task 4: File driver (read CSVs, filter to RELABEL, emit one CSV)

**Files:**
- Modify: `site/scripts/import_history.py`
- Test: `site/scripts/tests/test_import_history.py`

**Step 1: Write the failing test** (append)
```python
import csv as _csv
from import_history import convert_files

def test_convert_files_filters_and_relabels(tmp_path):
    src = tmp_path / "ew.csv"
    src.write_text("timestamp,run,co2,temp_in_c,humidity_pct\n"
                   "2026-06-01 01:00:00,eastwheelock_fan_closed_2ppl,812,22.5,44\n"
                   "2026-06-01 01:00:30,some_unmapped_run,900,22,45\n", encoding="utf-8")
    out = tmp_path / "out.csv"
    n = convert_files([str(src)], str(out))
    rows = list(_csv.DictReader(open(out, encoding="utf-8")))
    assert n == 1                                   # unmapped row skipped
    assert rows[0]["condition"] == "eastwheelock_fanclosed_2person"
    assert rows[0]["device_id"] == "ventis-01"
```

**Step 2: Run to verify it fails** — FAIL (`convert_files` undefined).

**Step 3: Minimal implementation** (append)
```python
def convert_files(paths, out_csv=OUT_CSV):
    out_rows = []
    for p in paths:
        with open(p, newline="", encoding="utf-8") as f:
            for raw in csv.DictReader(f):
                cond_col = "condition" if "condition" in raw else "run"
                raw_cond = str(raw.get(cond_col, "")).strip()
                if raw_cond not in RELABEL:
                    continue                        # only import the 4 target runs
                out_rows.append(map_row(raw, RELABEL[raw_cond]))
    os.makedirs(os.path.dirname(out_csv), exist_ok=True)
    with open(out_csv, "w", newline="", encoding="utf-8") as f:
        w = csv.DictWriter(f, fieldnames=COLUMNS, extrasaction="ignore")
        w.writeheader(); w.writerows(out_rows)
    return len(out_rows)

def main(argv):
    if "--csv" in argv:
        paths = argv[argv.index("--csv") + 1:]
    else:
        paths = sorted(glob.glob(os.path.join(ARCHIVE_DIR, "_history", "*.csv")))
    n = convert_files(paths)
    print(f"history import: {n} rows -> {OUT_CSV}")
    # per-condition summary
    import collections
    summary = collections.Counter()
    for p in paths:
        with open(p, newline="", encoding="utf-8") as f:
            for r in csv.DictReader(f):
                c = str(r.get("condition", r.get("run", ""))).strip()
                if c in RELABEL: summary[RELABEL[c]] += 1
    for k, v in sorted(summary.items()):
        print(f"  {k}: {v}")
    return 0

if __name__ == "__main__":
    sys.exit(main(sys.argv[1:]))
```

**Step 4: Run to verify it passes** — PASS (all import tests).

**Step 5: Commit**
```bash
git add site/scripts/import_history.py site/scripts/tests/test_import_history.py
git commit -m "feat(import): convert_files driver — filter to target runs + emit CSV"
```

---

### Task 5: Run against the real historical CSVs (smoke)

**Step 1:** Stage the 3 source CSVs into `archive/_history/` (gitignored) from the OneDrive backup:
```bash
mkdir -p site/scripts/archive/_history
python - <<'PY'
import zipfile
z = zipfile.ZipFile(r"C:/Users/turru/OneDrive/Ventis-Backups/ventis-FULL-dataset_2026-06-05_2112.zip")
for n in ["vault-Data/eastwheelock_fan_closed_2ppl.csv",
          "vault-Data/Ventis.v1 Logger - T window fan.csv",
          "vault-Data/ventis_data.csv"]:
    open("site/scripts/archive/_history/" + n.split("/")[-1], "wb").write(z.read(n))
print("staged 3 history CSVs")
PY
```
**Step 2:** `python site/scripts/import_history.py`
Expected: `history import: ~7994 rows -> .../history_import.csv` with per-condition counts:
`eastwheelock_fanclosed_2person: 1353`, `midmass_windowfan_3person: 2224`, `summit_bedroom_2person: 2363`, `little_baseline_1person: 2054`.
**Step 3:** Confirm `archive/_history/` and `history_import.csv` are gitignored (under `archive/`). No commit (artifacts only).

---

## Phase 3 — Cofounder guide

### Task 6: Write the paste-able Sheet guide

**Files:**
- Create: `docs/ventis-sheet-guide.md`

**Step 1:** Write `docs/ventis-sheet-guide.md` containing:
- **Labeling rule:** `building_condition_occupancy`, all lowercase, NEVER names/room numbers (anonymization cardinal rule). Examples: `little_baseline_1person`, `eastwheelock_fanclosed_2person`.
- **Building slugs:** the `KNOWN_BUILDINGS` list (consistent names; "if your building isn't here, add it lowercase, no spaces").
- **Start/stop a run:** edit the `control` tab **ROW 2** only — `A2`=logging (start/stop), `B2`=label, `C2`=**bump `seq` to a new higher number** (device compares vs NVS-persisted value). Editing any other row does nothing.
- **Handoff:** run `/ventis-backup` after a run.

**Step 2: Commit**
```bash
git add docs/ventis-sheet-guide.md
git commit -m "docs(import): paste-able in-Sheet cofounder labeling + start/stop guide"
```

---

## Phase 4 — Integrate + verify (needs Diego for the paste)

### Task 7: Paste + verify locally

**Step 1 (Diego):** Open `archive/history_import.csv`, copy its data rows (not the header), and **append** them to the Sheet's `telemetry` tab. Create a `guide` tab and paste `docs/ventis-sheet-guide.md`.
**Step 2:** `VENTIS_SHEET_ID=<id> python site/scripts/sqlite_sync.py`
Expected: `runs: 6` — conditions include all 6 canonical labels.
**Step 3:** `python site/scripts/build_catalog.py` → `catalog built: 6 runs`. Verify buildings:
```bash
python -c "import json;[print(r['building'],r['occupancy'],r['condition']) for r in json.load(open('library/public/data/catalog.json'))['runs']]"
```
Expected: `fahey 1 ...`, `judge 2 ...`, `eastwheelock 2 ...`, `summit 2 ...`, `little 1 ...`, `midmass 3 ...`.

### Task 8: Finish + deploy
- Run full suites: `python -m pytest site/scripts/tests/ -v` (all pass) ; `cd library && npm test`.
- Use superpowers:finishing-a-development-branch → PR `feat-history-import` → `main`.
- After merge: manual `workflow_dispatch` → live catalog shows all 6 runs with correct buildings.
- Update memory + vault `Data/Data Library — Design.md` (note: 6 runs live).

---

## Notes
- DRY: reuse `sqlite_sync`/`build_catalog`; the importer only maps + relabels.
- YAGNI: no Sheet auto-write, no editing existing Fahey/Judge rows, no exhaustive hall list.
- Anonymization is enforced at import (device_id=ventis-01, consent=anon, canonical labels) — the cardinal rule.

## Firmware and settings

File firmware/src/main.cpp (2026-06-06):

#include <Arduino.h>
#include <Wire.h>
#include <WiFi.h>
#include <HTTPClient.h>
#include <WiFiClientSecure.h>
#include <ArduinoJson.h>
#include <time.h>
#include <OneWire.h>
#include <DallasTemperature.h>
#include <SensirionI2CScd4x.h>
#include <Adafruit_SSD1306.h>
#include <ESPAsyncWebServer.h>
#include <Preferences.h>
#include <LittleFS.h>
#include "config.h"

#ifndef ANTHROPIC_MODEL
#define ANTHROPIC_MODEL "claude-haiku-4-5-20251001"
#endif

inline float toF(float c) { return c * 9.0f / 5.0f + 32.0f; }

// ── Sensors ──────────────────────────────────────────────────────────────────

SensirionI2cScd4x scd40;
OneWire           oneWire(PIN_DS18B20);
DallasTemperature ds18b20(&oneWire);
Adafruit_SSD1306  oled(OLED_WIDTH, OLED_HEIGHT, &Wire, -1);
AsyncWebServer    server(80);

// ── State ────────────────────────────────────────────────────────────────────

struct Readings {
    uint16_t co2          = 0;
    float    tempIn       = 0.0f;   // °C, from SCD40
    float    humidity     = 0.0f;   // %RH
    float    tempOut      = 0.0f;   // °C, from wireless C3 or wired DS18B20
    bool     tempOutValid = false;  // false when no fresh outdoor source — disables COOLING mode
    bool     valid        = false;
} readings;

enum FanReason { NONE, COOLING, CO2_HIGH, HUMIDITY_HIGH, MANUAL };
enum SwitchMode { SW_AUTO, SW_FORCE_ON };
enum OverrideMode { OVR_AUTO, OVR_ON, OVR_OFF };

SwitchMode readSwitch() {
    return digitalRead(PIN_SWITCH_ON) == LOW ? SW_FORCE_ON : SW_AUTO;
}

struct FanState {
    bool      on     = false;
    FanReason reason = NONE;
} fan;

OverrideMode override_mode = OVR_AUTO;  // set via POST /control?mode=auto|on|off

// User-set indoor cooling setpoint. Fan triggers COOLING only when indoor > setpoint
// AND outdoor is colder by COOLING_DELTA_C. Default 75°F (23.89°C). Range 60-90°F.
float coolingSetpointC = 23.89f;
const float SETPOINT_MIN_F = 60.0f;
const float SETPOINT_MAX_F = 90.0f;

// User-set manual-mode fan duty (0-255). Default 255 = 100% to preserve old behavior.
// Only takes effect when override_mode == OVR_ON; ignored in auto and off modes.
uint8_t manualDuty = FAN_DUTY_MAX;

// History ring buffer — 60 samples × 5s cadence = 5 min rolling window
#define HISTORY_SIZE 60
struct HistorySample {
    unsigned long t_ms;       // millis() at capture
    uint16_t      co2;
    float         tempIn;     // °C
    float         humidity;   // %RH
    float         tempOut;    // °C
    bool          fanOn;
};
HistorySample history[HISTORY_SIZE];
uint8_t       historyHead = 0;
bool          historyFull = false;

unsigned long lastScd40Read   = 0;
unsigned long lastDs18b20Read = 0;

float         tempOutWired     = 0.0f;   // from wired DS18B20 (currently NOT wired on v1 hub)
bool          tempOutWiredValid = false;  // set true on first successful DS18B20 read
unsigned long lastWiredOkMs    = 0;      // millis() of most recent successful DS18B20 read
float         tempOutWireless  = 0.0f;   // from C3 outdoor node
unsigned long lastOutdoorPostMs = 0;      // 0 = never received

bool          oledOk           = false;   // set by probe in setup(); guards all OLED I2C ops
unsigned long lastLogMs        = 0;
bool          logEnabled       = false;

// Latest insight cache — populated by /insight POST handler AND by periodic
// auto-trigger in loop(). Served via /data so viewer clients see live content
// even when no controller has tapped. Source surfaces "live" (Anthropic ok),
// "fallback" (rule-based degradation when WiFi/API failed), or "init" (boot,
// no insight generated yet). Dashboard maps these to a visible chip so judges
// see graceful degradation as a feature, not a bug.
String cachedInsightText   = "Just booting up. First reading in a moment.";
String cachedInsightSource = "init";
char   cachedInsightTs[25] = "boot";

// Auto-regen: one boot trigger ~8s after first valid SCD40 reading, then every
// AUTO_INSIGHT_INTERVAL_MS. Keeps viewer dashboards fresh even when controller
// hasn't tapped. Each call blocks loop() ~2-3s for the Anthropic round-trip;
// SCD40 5s cadence absorbs that, AsyncTCP /data polling continues uninterrupted.
unsigned long lastAutoInsightMs    = 0;
unsigned long firstValidReadingMs  = 0;
bool          autoInsightBootDone  = false;
const unsigned long AUTO_INSIGHT_INTERVAL_MS   = 60000;  // 60s between periodic auto-regens
const unsigned long AUTO_INSIGHT_BOOT_DELAY_MS = 8000;   // wait 8s after first reading before first auto
char          runLabel[64]     = "unlabeled";
char          runId[40]        = "";        // <DEVICE_ID>_<start_epoch>, set on run start, persisted in NVS
uint32_t      logRowCount      = 0;

// Logging persistence (NVS) + remote control. logEnabled/runLabel survive a
// reboot so a crash or power-blip RESUMES the run instead of going silent; the
// device also polls the Apps Script doGet for start/stop commands so a run can be
// controlled from anywhere (outbound HTTPS — no LAN/inbound access needed).
Preferences   prefs;
uint32_t      lastCtrlSeq      = 0;       // last applied remote command id
unsigned long lastCtrlPollMs   = 0;

// /insight is handled synchronously in the AsyncWebServer handler — see setupServer().
// Previous async/loop-dispatch architecture had a dangling-pointer + TCP-tear-down
// bug that dropped responses to the browser. Sync handler trades 2-3s of /data
// polling pause for end-to-end reliability.

// ── Control logic ─────────────────────────────────────────────────────────────

FanState evaluateFan(const Readings &r) {
    FanState s;
    if (!r.valid) return s;

    if (r.co2 > CO2_THRESHOLD) {
        s.on = true; s.reason = CO2_HIGH; return s;
    }
    if (r.humidity > HUMIDITY_THRESHOLD) {
        s.on = true; s.reason = HUMIDITY_HIGH; return s;
    }
    // Cool only when (a) we have valid outdoor reading, (b) indoor is above the
    // user's comfort setpoint, AND (c) outdoor air is actually colder by ΔT.
    if (r.tempOutValid
        && r.tempIn > coolingSetpointC
        && (r.tempIn - r.tempOut) > COOLING_DELTA_C) {
        s.on = true; s.reason = COOLING; return s;
    }
    return s;
}

const char *reasonStr(FanReason r) {
    switch (r) {
        case CO2_HIGH:      return "CO2";
        case HUMIDITY_HIGH: return "HUMIDITY";
        case COOLING:       return "COOLING";
        case MANUAL:        return "MANUAL";
        default:            return "---";
    }
}

// PWM duty selection — relay still gates 12V (true off), PWM scales speed when fan.on.
// NF-P12 Redux doesn't fully stop at duty 0, so relay + PWM both matter.
uint8_t computeDuty(const FanState &f, const Readings &r) {
    if (!f.on) return 0;
    if (f.reason == MANUAL) return manualDuty;  // user-set 0-255 via dashboard slider
    if (f.reason == CO2_HIGH && r.co2 >= CO2_ALARM_PPM) return FAN_DUTY_MAX;
    if (f.reason == COOLING) return FAN_DUTY_MAX;
    return FAN_DUTY_MID;
}

void setFanOutputs(const FanState &f, const Readings &r) {
    digitalWrite(PIN_RELAY, f.on ? RELAY_ON : RELAY_OFF);
    ledcWrite(FAN_PWM_CHANNEL, computeDuty(f, r));
}

void pushHistory(const Readings &r, bool fanOn) {
    HistorySample &s = history[historyHead];
    s.t_ms     = millis();
    s.co2      = r.co2;
    s.tempIn   = r.tempIn;
    s.humidity = r.humidity;
    s.tempOut  = r.tempOut;
    s.fanOn    = fanOn;
    historyHead = (historyHead + 1) % HISTORY_SIZE;
    if (historyHead == 0) historyFull = true;
}

// ── Google Sheets logger ─────────────────────────────────────────────────────

void logToSheets() {
    if (!readings.valid || strlen(SHEETS_URL) == 0) return;
    char ts[25] = "unknown";
    struct tm t;
    if (getLocalTime(&t)) strftime(ts, sizeof(ts), "%Y-%m-%dT%H:%M:%S", &t);
    char body[448];
    snprintf(body, sizeof(body),
        "{\"token\":\"%s\",\"device_id\":\"%s\",\"run_id\":\"%s\",\"timestamp\":\"%s\",\"run\":\"%s\",\"co2\":%u,\"temp_in_c\":%.2f,"
        "\"humidity_pct\":%.2f,\"temp_out_c\":%.2f,\"fan_on\":%s,\"fan_duty\":%u,\"reason\":\"%s\"}",
        SHEETS_TOKEN, DEVICE_ID, runId, ts, runLabel, readings.co2, readings.tempIn, readings.humidity, readings.tempOut,
        fan.on ? "true" : "false", computeDuty(fan, readings), reasonStr(fan.reason));
    WiFiClientSecure client;
    client.setInsecure();
    HTTPClient http;
    http.begin(client, SHEETS_URL);
    http.setFollowRedirects(HTTPC_STRICT_FOLLOW_REDIRECTS);
    http.addHeader("Content-Type", "application/json");
    http.POST(body);
    http.end();
    Serial.printf("[LOG] %s co2=%u\n", ts, readings.co2);
}

// ── Logging state persistence + remote control ───────────────────────────────

void persistLogState() {
    prefs.putBool("logOn", logEnabled);
    prefs.putString("label", runLabel);
    prefs.putString("runId", runId);
}

// Single path for applying a logging command, whether it came from the on-device
// web UI or the remote control tab. Persists to NVS so it survives a reboot.
void applyLogCommand(bool enable, const char *label, bool resetCounters) {
    if (label && label[0]) {
        strncpy(runLabel, label, sizeof(runLabel) - 1);
        runLabel[sizeof(runLabel) - 1] = '\0';
    }
    if (enable && (!logEnabled || resetCounters)) {
        logRowCount = 0;
        lastLogMs   = 0;   // log immediately on (re)start
        // New run → mint a run_id (<device>_<start epoch>). Persisted below, so a reboot
        // mid-run RESUMES the same run_id rather than splitting the run. Falls back to
        // uptime millis if NTP hasn't synced yet (run_id stays unique, just not wall-clock).
        time_t now = time(nullptr);
        long stamp = (now > 1700000000) ? (long)now : (long)millis();
        snprintf(runId, sizeof(runId), "%s_%ld", DEVICE_ID, stamp);
    }
    logEnabled = enable;
    persistLogState();
}

// Poll the Apps Script doGet for a remote logging command. Outbound HTTPS, so it
// works from anywhere the device has internet — no inbound/LAN access needed. A
// command applies only when its `seq` increments, so it never fights the on-device
// web UI: you trigger it by editing the control tab and bumping seq.
void pollControl() {
    if (strlen(SHEETS_URL) == 0 || WiFi.status() != WL_CONNECTED) return;
    WiFiClientSecure client;
    client.setInsecure();
    HTTPClient http;
    if (!http.begin(client, SHEETS_URL)) return;
    http.setFollowRedirects(HTTPC_STRICT_FOLLOW_REDIRECTS);
    int code = http.GET();
    if (code == 200) {
        JsonDocument doc;
        if (deserializeJson(doc, http.getString()) == DeserializationError::Ok) {
            uint32_t seq = doc["seq"] | 0;
            if (seq != lastCtrlSeq) {
                bool        enable = doc["logging"] | false;
                const char *label  = doc["label"]  | "";
                applyLogCommand(enable, label, true);
                lastCtrlSeq = seq;
                prefs.putUInt("ctrlSeq", lastCtrlSeq);
                Serial.printf("[CTRL] seq %u: logging=%s label=%s\n",
                              seq, enable ? "ON" : "OFF", runLabel);
            }
        }
    }
    http.end();
}

// ── RGB LED ──────────────────────────────────────────────────────────────────

void updateLed(uint16_t co2, bool valid) {
    // ledc PWM — channels 2=R, 3=G (timer 1). Channels 0 + 1 are off-limits:
    // channel 0 belongs to fan PWM, channel 1 shares timer 0 with channel 0.
    if (!valid || logEnabled) {
        ledcWrite(2, 0); ledcWrite(3, 0); digitalWrite(PIN_LED_B, LOW);
        return;
    }
    // Green <800 | Amber 800-999 | Red ≥1000. 20 ppm hysteresis on downward edges.
    static uint8_t state = 0;  // 0=green, 1=amber, 2=red
    if (state == 0) {
        if (co2 >= CO2_ALARM_PPM)       state = 2;
        else if (co2 >= CO2_THRESHOLD)  state = 1;
    } else if (state == 1) {
        if (co2 >= CO2_ALARM_PPM)             state = 2;
        else if (co2 < CO2_THRESHOLD - 20)    state = 0;
    } else {
        if (co2 < CO2_ALARM_PPM - 20)         state = 1;
    }
    if (state == 2) {       ledcWrite(2, 255); ledcWrite(3, 0); }
    else if (state == 1) {  ledcWrite(2, 255); ledcWrite(3, 40);  }  // amber: red-dominant, small green for warm tint
    else {                  ledcWrite(2, 0);   ledcWrite(3, 255); }
    digitalWrite(PIN_LED_B, LOW);
    static uint8_t lastLogged = 255;
    if (state != lastLogged) { Serial.printf("[LED] state=%d co2=%u\n", state, co2); lastLogged = state; }
}

// ── OLED ─────────────────────────────────────────────────────────────────────

void updateOled() {
    if (!oledOk) return;
    oled.clearDisplay();
    oled.setTextSize(1);
    oled.setTextColor(SSD1306_WHITE);
    oled.setCursor(0, 0);

    oled.printf("CO2:  %4u ppm\n",   readings.co2);
    oled.printf("IN:   %.1fF  %.0f%%\n", toF(readings.tempIn), readings.humidity);
    if (readings.tempOutValid) oled.printf("OUT:  %.1fF\n", toF(readings.tempOut));
    else                       oled.printf("OUT:  --  offline\n");
    oled.printf("FAN:  %s  %s\n",
        fan.on ? "ON " : "OFF",
        fan.on ? reasonStr(fan.reason) : "");
    oled.printf("IP: %s\n", WiFi.localIP().toString().c_str());
    if (logEnabled) {
        oled.printf("LOG: %s (%u)\n", runLabel, logRowCount);
    }

    oled.display();
}

// ── /insight helpers ─────────────────────────────────────────────────────────

// Used when ANTHROPIC_API_KEY is missing, WiFi is down, or the API call fails.
// Cites real sensor numbers instead of generic baked text.
String fallbackInsight() {
    String s;
    if (!readings.valid) {
        s = "Sensors are still warming up — give it a moment.";
    } else if (readings.co2 >= CO2_ALARM_PPM) {
        s = "CO2 is elevated at " + String(readings.co2) + " ppm. ";
        s += fan.on ? "Fan is running to flush the room." : "Consider switching to manual on or opening a window.";
    } else if (readings.co2 >= CO2_THRESHOLD) {
        s = "CO2 climbing — " + String(readings.co2) + " ppm. ";
        s += fan.on ? "Fan kicked on automatically." : "Below the active-ventilation threshold for now.";
    } else {
        s = "Air looks good: " + String(readings.co2) + " ppm CO2, "
          + String(toF(readings.tempIn), 0) + "F indoor, " + String((int)readings.humidity) + "% RH.";
    }
    return s;
}
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
void loop() {
    unsigned long now = millis();

    // Read SCD40
    if (now - lastScd40Read >= INTERVAL_SCD40) {
        lastScd40Read = now;
        uint16_t co2;
        float    temp, hum;
        bool     dataReady = false;

        scd40.getDataReadyStatus(dataReady);
        if (dataReady) {
            uint16_t err = scd40.readMeasurement(co2, temp, hum);
            if (err == 0) {
                readings.co2      = co2;
                readings.tempIn   = temp;
                readings.humidity = hum;
                readings.valid    = true;
            }
        }
    }

    // Read DS18B20 (only if a probe was found at boot — v1 hub has no wired probe)
    if (now - lastDs18b20Read >= INTERVAL_DS18B20 && ds18b20.getDeviceCount() > 0) {
        lastDs18b20Read = now;
        ds18b20.requestTemperatures();
        float t = ds18b20.getTempCByIndex(0);
        if (t != DEVICE_DISCONNECTED_C) {
            tempOutWired      = t;
            tempOutWiredValid = true;
            lastWiredOkMs     = now;
        }
    }

    // Prefer wireless when fresh; fall back to wired if C3 is silent; mark invalid if neither
    bool wirelessFresh = lastOutdoorPostMs > 0 &&
                         (now - lastOutdoorPostMs < OUTDOOR_STALE_MS);
    bool wiredFresh    = tempOutWiredValid &&
                         (now - lastWiredOkMs < OUTDOOR_STALE_MS);
    if (wirelessFresh)   { readings.tempOut = tempOutWireless; readings.tempOutValid = true; }
    else if (wiredFresh) { readings.tempOut = tempOutWired;    readings.tempOutValid = true; }
    else                 { readings.tempOutValid = false; }

    // Control logic — web override > physical switch > auto
    if (override_mode == OVR_ON) {
        fan.on = true;   fan.reason = MANUAL;
    } else if (override_mode == OVR_OFF) {
        fan.on = false;  fan.reason = NONE;
    } else if (readSwitch() == SW_FORCE_ON) {
        fan.on = true;   fan.reason = MANUAL;
    } else {
        fan = evaluateFan(readings);
    }
    setFanOutputs(fan, readings);  // relay = master enable, PWM = variable speed

    // Push to history ring buffer on every SCD40 read (5s cadence)
    static unsigned long lastHistoryPush = 0;
    if (readings.valid && now - lastHistoryPush >= INTERVAL_SCD40) {
        lastHistoryPush = now;
        pushHistory(readings, fan.on);
    }

    // Google Sheets logging
    if (logEnabled && readings.valid && (now - lastLogMs >= LOG_INTERVAL)) {
        lastLogMs = now;
        logToSheets();
        logRowCount++;
    }

    // Remote control poll — outbound HTTPS, so a run can be started/stopped from
    // anywhere (edit the control tab + bump seq). Blocks ~1-2s like logToSheets.
    if (now - lastCtrlPollMs >= CTRL_POLL_INTERVAL) {
        lastCtrlPollMs = now;
        pollControl();
    }

    // RGB LED
    updateLed(readings.co2, readings.valid);

    // OLED redraws on its own cadence (decoupled from SCD40) so fan / state
    // transitions land within 1s on the screen even though sensor data is 5s.
    static unsigned long lastOledUpdate = 0;
    if (now - lastOledUpdate >= INTERVAL_OLED) {
        lastOledUpdate = now;
        updateOled();
    }

    // Auto-regen insight (boot + every 60s). Last in loop iteration so it doesn't
    // delay LED/OLED/control updates above. Blocks loop ~2-3s per fire.
    maybeAutoInsight(now);
}

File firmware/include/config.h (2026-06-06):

#pragma once

// Secrets (WiFi credentials, Anthropic API key) live in secrets.h, which is gitignored.
// Copy secrets.h.example to secrets.h on a fresh clone before building.
#include "secrets.h"

// Pin assignments — core
#define PIN_DS18B20   4     // DS18B20 OneWire data
#define PIN_RELAY     26    // Relay control — switches 12V DC to Noctua (was AC mains pre-2026-05-25)

// Pin assignments — v1 indicators + override
#define PIN_LED_R         19    // RGB LED red channel (common cathode, active HIGH)
#define PIN_LED_G         17    // RGB LED green channel
#define PIN_LED_B         16    // RGB LED blue channel
#define PIN_SWITCH_ON     32    // 2-pos switch: LOW = manual fan ON, HIGH = auto

// Pin assignments — Noctua NF-P12 Redux 1700 PWM (4-pin, 12V, native PWM)
#define PIN_FAN_PWM       25    // PWM out → fan pin 4 (Blue); 25 kHz, 3.3V logic
#define PIN_FAN_TACH      34    // Tach in ← fan pin 3 (Green); ext 10kΩ pull-up to 3.3V (input-only pin, no internal pull-up)

// HiLetgo OPTO relay jumper set to HIGH trigger: HIGH = fan ON, LOW = fan OFF
#define RELAY_ON      HIGH
#define RELAY_OFF     LOW

// Fan PWM (LEDC peripheral)
#define FAN_PWM_CHANNEL   0       // ESP32 LEDC channel
#define FAN_PWM_FREQ      25000   // Hz — Noctua PWM spec
#define FAN_PWM_RES_BITS  8       // → duty range 0-255
#define FAN_DUTY_MID      128     // ~50% — normal active modes (cooling, humidity, CO2 elevated)
#define FAN_DUTY_MAX      255     // 100% — CO2 alarm or manual override

// I2C bus (SCD40 + OLED share the same bus)
#define PIN_SDA       21
#define PIN_SCL       22
#define OLED_ADDR     0x3C
#define OLED_WIDTH    128
#define OLED_HEIGHT   64

// Control thresholds
#define COOLING_DELTA_C    2.8f   // ~5°F — fan ON only if indoor exceeds outdoor by this much (matches Firmware v2 spec; 5°F is the honest floor for felt convective cooling + keeps headroom above the 3°F hysteresis floor)
#define CO2_THRESHOLD      800    // ppm — fan ON above this level
#define CO2_ALARM_PPM      1000   // ppm — red LED alarm
#define HUMIDITY_THRESHOLD 65.0f  // %RH — fan ON above this level

// Sensor read intervals (ms)
#define INTERVAL_SCD40    5000   // SCD40 periodic measurement cadence (hardware floor — NDIR cycle)
#define INTERVAL_DS18B20  10000  // Outdoor temp poll. NOTE: if outdoor node moves to battery, revert to 30000+ to extend C3 runtime.
#define INTERVAL_OLED     1000   // OLED redraw cadence (decoupled from sensor read — repaints cached readings + live state)

// Google Sheets logger
// 2026-06-01: repointed to the v3 schema deployment (writes the locked `telemetry` tab).
// Old per-run-tab deployment was: AKfycbwBiCM6SlmVnw8-vi2htEFvyK16HTt9hWD-U46EZVeYU6-Zm8fLjJlekcMcTeHTh_II
#define SHEETS_URL   "https://script.google.com/macros/s/AKfycbxGhE2Pz5Lp1xlLEwjpfPZI9cyJkNz3nbioRvHkJfGn5dgp94_JDueu67judZPQumFmWQ/exec"
#define DEVICE_ID    "ventis-01"        // pseudonym; namespaces run_id + the row's device_id. NO real names.
#define RUN_LABEL    "unlabeled"      // change before each run: e.g. "dorm_window_only"
#define LOG_INTERVAL 30000            // ms between log writes (30s matches old Pi logger)
#define CTRL_POLL_INTERVAL 60000      // ms between remote-control polls (Apps Script doGet)

// Ventis AP — private network for outdoor node (AP+STA dual mode)
#define AP_SSID          "Ventis"
#define AP_PASSWORD      "ventis-outdoor"
#define OUTDOOR_STALE_MS 90000   // ms — fall back to wired DS18B20 if C3 silent

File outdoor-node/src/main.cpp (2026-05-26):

#include <Arduino.h>
#include <WiFi.h>
#include <HTTPClient.h>
#include <OneWire.h>
#include <DallasTemperature.h>
#include "config.h"

OneWire           oneWire(PIN_DS18B20);
DallasTemperature ds18b20(&oneWire);

void measure_and_post() {
    // Read DS18B20
    ds18b20.requestTemperatures();
    float tempC = ds18b20.getTempCByIndex(0);
    Serial.printf("DS18B20: %.2f C\n", tempC);

    if (tempC == DEVICE_DISCONNECTED_C) {
        Serial.println("DS18B20 disconnected");
#if !DEBUG_NO_SLEEP
        esp_sleep_enable_timer_wakeup((uint64_t)SLEEP_INTERVAL_S * 1000000ULL);
        esp_deep_sleep_start();
#endif
        return;
    }

    // Connect to Ventis AP
    WiFi.begin(AP_SSID, AP_PASSWORD);
    Serial.print("Connecting");
    unsigned long start = millis();
    while (WiFi.status() != WL_CONNECTED && millis() - start < 10000) {
        delay(500);
        Serial.print(".");
    }

    if (WiFi.status() == WL_CONNECTED) {
        Serial.println("\nConnected to Ventis AP");
        HTTPClient http;
        String url = "http://";
        url += HUB_IP;
        url += "/outdoor?temp_c=";
        url += String(tempC, 2);
        http.begin(url);
        int code = http.POST("");
        Serial.printf("POST %s → %d\n", url.c_str(), code);
        http.end();
        WiFi.disconnect(true);
        WiFi.mode(WIFI_OFF);
    } else {
        Serial.println("\nAP connect failed");
    }
}

void setup() {
    Serial.begin(115200);
    delay(100);
    ds18b20.begin();

#if DEBUG_NO_SLEEP
    Serial.println("=== DEBUG_NO_SLEEP MODE — deep sleep DISABLED ===");
    Serial.printf("Looping every %d ms. Revert by setting DEBUG_NO_SLEEP=0 in config.h.\n", DEBUG_LOOP_MS);
#else
    measure_and_post();
    Serial.printf("Sleeping %ds\n", SLEEP_INTERVAL_S);
    Serial.flush();
    esp_sleep_enable_timer_wakeup((uint64_t)SLEEP_INTERVAL_S * 1000000ULL);
    esp_deep_sleep_start();
#endif
}

void loop() {
#if DEBUG_NO_SLEEP
    measure_and_post();
    Serial.println("---");
    delay(DEBUG_LOOP_MS);
#endif
}

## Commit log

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2026-05-26 feat(insight): live on-device Claude API for /insight endpoint
    Replaces the baked-stub handler with a live Anthropic Haiku 4.5 call,
    deferred from the AsyncWebServer to loop() so the 2-3s HTTPS POST doesn't
    block AsyncTCP. Sensor-aware fallback covers WiFi/API failures. The system
    prompt was locked after two rounds of tuning against six synthetic scenarios
    via dev/test_insight_prompt.py, which mirrors the firmware request body so
    re-tuning never requires re-flashing.
    [main.cpp]
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2026-05-27 feat(dodi): step 5 — GSAP state machine + tint/sweat + body-group
    - Wraps feathers, head, beak, body, belly shadow, eyes in
    <g class="body-group"> so GSAP can target it for bobble + shake
    - Adds tint overlay (32x36 olive-yellow at 0.32 opacity) and sweat
    drop sprite, both hidden by default, shown on .distress class
    - initDodiTimelines() sets up:
    * idle yoyo bobble on body-group (1.25s sine.inOut, infinite)
    * wing flap via gsap.to({},{onRepeat}) swapping wing-up/wing-down
    display every 90ms while .flapping class is present
    * body shake (rapid x oscillation) while .distress class is present
    * MutationObserver on #dodo-pixel class for state syncing
    - Adds parallel #dodo-pixel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
    [main.cpp]
2026-05-27 feat(dodi): step 6 — swap to pixel-art Dodi, remove SVG version
    Pixel-art Dodi is now THE Dodi.
    - Removes the old SVG Dodi <div> block entirely (~50 lines of inline
    SVG with ellipses, paths, and the gas-mask group)
    - Removes 'hidden' attribute from pixel-art Dodi wrapper
    - Removes the now-dead if(dodo){...} state-update block in refreshData
    - Removes SVG-Dodi-only CSS: keyframes (dodo-bobble, wing-idle-l/r,
    wing-flap-l/r, futile-fly), .body and .wing-l/r animation rules,
    .gas-mask styles. Pixel-art Dodi uses GSAP for all motion instead.
    Build verified clean: RAM 15.2%, Flash 81.4% (compile succeeded).
    [main.cpp]
2026-05-27 fix(dodi): adjust dodo-wrap overlap for smaller pixel-art sprite
    Old SVG Dodi was 80x88 with margin-bottom:-14px. Pixel-art Dodi is
    64x72 — the same negative margin overshoots and pushes feet inside
    the CO2 panel instead of perching on its top edge.
    Reduced to -6px so feet kiss the panel edge cleanly.
    [main.cpp]
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2026-05-27 feat(dodi): restyle step 6 — swap to v2 realistic dodo
    Removed v1 chibi sprite, unhid v2, retargeted GSAP timelines and
    refreshData state update to #dodo-pixel-v2.
    [main.cpp]
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2026-05-27 feat(dashboard): D — full layout redesign per Claude Design mockup
    - Location label in header (replaces LIVE pulse — was redundant)
    - Dodi callout tile: pixel-art Dodi + status text alongside (label /
    title / sub) with state-driven background tint (green/amber/red)
    - CO2 tile redesigned: left-aligned, value + ppm + sub-status, badge
    (GOOD/AMBER/HIGH), embedded 60px mini chart
    - Temp + Humidity row replaces Indoor + Outdoor (outdoor still in
    data API for logging, just not displayed)
    - AI Insight tile always visible with green dot + ON-DEVICE badge.
    Auto-fetches on state changes (with 25s throttle). No more
    Generate button click required.
    - Standalone chart tile removed (chart no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
    [main.cpp]
2026-05-27 fix(states): add 20ppm hysteresis to LED + dashboard tier
    [main.cpp]
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2026-05-28 fix(led): use ledcWrite instead of analogWrite for reliable PWM on GPIO 17
    [main.cpp]
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2026-05-28 fix(led): drop R duty to 3 for amber, add state transition serial log
    [main.cpp]
2026-05-28 fix(led): move ledc init to setup() so pin mux is owned by LEDC from boot
    pinMode + digitalWrite before ledcAttachPin can leave the pin stuck in
    digital mode on ESP32 Arduino — explains why green LED wasn't responding
    to ledcWrite. R works either way because HIGH/LOW map cleanly to PWM
    0/255 boundaries by coincidence.
    [main.cpp]
2026-05-28 fix(led): move LED PWM to channels 2+3 — channel 0 collision with fan PWM
    Root cause: fan PWM uses channel 0, LED R was also on channel 0.
    Fan setup ran after LED setup → fan stole channel 0 → GPIO 19 (R LED)
    left floating + ledcWrite to channel 0 wrote duty to GPIO 25 (fan) instead.
    This is why LED appeared 'dim red blinking' regardless of state.
    [main.cpp]
2026-05-28 feat(speed): faster updates — dashboard 1s, OLED 1s, DS18B20 10s
    - Dashboard /data poll: 2s → 1s
    - OLED redraw: decoupled from SCD40 5s cadence, now updates every 1s
    (cached sensor readings + live fan/relay state)
    - DS18B20 outdoor temp: 30s → 10s. Note in config: revert to 30s+ if
    outdoor node ever moves to battery power.
    - SCD40 stays at 5s — hardware NDIR cycle floor, can't go faster.
    [config.h, main.cpp]
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2026-05-29 fix(cooling): COOLING_DELTA 3°F -> 5°F to match v2 spec
    Resolves the long-open v1/v2 contradiction. Free-cooling at a 3°F
    indoor-outdoor gradient is imperceptible after convective mixing + fan
    motor heat; 5°F is the honest felt-cooling floor and keeps headroom above
    the spec's 3°F hysteresis OFF point. One canonical value across v1 and v2.
    [config.h]
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2026-06-02 fix(firmware): repoint SHEETS_URL to v3 schema deployment
    The v3 telemetry-schema Code.gs was deployed to a new /exec URL, but the firmware still posted to the old per-run-tab deployment, so the schema script was never hit (no telemetry tab, empty executions). Repointed SHEETS_URL to the v3 deployment; verified live via test POST (HTTP 200). Old URL preserved in a comment.
    [config.h]
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2026-06-03 feat(firmware+app): serve React UI from ESP32 LittleFS + Dodi/tip fixes
    - Firmware serves the built React app from LittleFS via serveStatic
    instead of the embedded HTML dashboard. main.cpp mounts LittleFS and
    registers serveStatic("/") after the JSON API routes; legacy INDEX_HTML
    kept in-source but unregistered. platformio.ini: board_build.filesystem
    = littlefs. Single device serves the UI at 192.168.4.1 (AP) — no laptop.
    - DodiBubble: fix tip bubbles never dismissing (auto-dismiss timer reset on
    every sensor-poll re-render). Timer keyed on `text` via a ref; added
    tap-to-dismiss; pointer-events enabled only while visible.
    - Decouple Dodi tips from control: CO2/temp/fan/insight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
    [main.cpp]
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2026-06-04 feat(site): add CO2 performance/cognition evidence block to Problem page
    Cited (LBNL 2012, 2023 bedroom-ventilation field study): frames CO2 as a student-performance/academic issue — the institutional ROI hook.
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2026-06-04 feat(site): add v1 hardware photo + v1→v2→v3 roadmap to How It Works
    - "The hardware, today": real v1-prototype photo (1600px, 247KB) with
    honest caption — senses/decides/drives the fan; window-duct unit in dev
    - "Where Ventis is headed": v1→v2→v3 roadmap, v2 emphasized as the window
    unit ("first units expected Fall 2026", framed as target, no pricing)
    - v3 = heat-recovery vision (brief)
    - closing note reinforces not-an-AC framing (no heating element/refrigerant)
2026-06-04 feat(site): ship interactive scrubbable demo on /demo
    Replaces the placeholder with a self-contained replay of the real Fahey
    overnight run (measured, not simulated):
    - device-style readout: live CO2 number, Fresh/Elevated level pill, fan
    state, clock, trend arrow — all driven from real telemetry
    - Dodi narration keyed to window phase; honest per canon (closed-room
    climb = shut window, reopen flush = air-exchange proof; never presents
    the recirc fan as lowering CO2)
    - progressive area chart with moving playhead, phase shading, ASHRAE line
    - play/pause + scrubber transport; no hardware or backend needed
    Live-feed bolt-on (fetchLiveRun) remains the documented Phase-2 follow-up.
    Co-Au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
2026-06-04 feat(site): rebuild /demo as faithful on-device dashboard replica
    Replaces the bespoke chart player with a phone-framed replica of the
    actual ESP32 LiveView UI (Joy's current dashboard, view-only mode):
    - ported cards: Dodi sleep callout, CO2 + cognitive-focus + banded
    sparkline, indoor temp + humidity tiles, fan running/idle, on-device
    Dodi insight (REPLAY-tagged for honesty)
    - device tier logic (hysteresis) precomputed across the run
    - driven by play/scrub over the real Fahey overnight run, now incl.
    measured temp + humidity (extract_runs.py extended; CO2/fan unchanged
    so /data is unaffected). No fabricated values; no outdoor temp shown
    for Fahey (not logged) — window story car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
2026-06-04 docs+copy: add design/voice guide and de-AI the site copy
    - site/DESIGN.md: design system + voice standard + claim-integrity rule
    + pre-ship checklist (distills the ui-ux-pro-max quality checklist;
    documents the real tokens/type/motion so the site reads intentional)
    - copy pass across all pages + run captions: em-dashes 51->22, the
    "X vs Y" antithesis kept once (evidence headline), "honest" thinned,
    leftover warning emoji removed. Voice preserved.
    - no factual claims changed; numbers/citations identical. One tightening:
    "every dorm built before central air" -> "most dorms predate central
    air" (East Wheelock has real mechanical ventilation).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
2026-06-04 copy: finish the em-dash pass across all site copy
    Second pass — removes every remaining em-dash from user-facing copy
    (footer, How flow/feels/roadmap, Demo captions + the data-page pointer,
    Home panel desc, Problem citations, Contact success messages, DeviceDemo
    Dodi insight strings) and the run names (— -> middot, matching the peak
    line separator). Also drops a stray "honestly" in the footer.
    Em-dashes in user-facing copy: 22 -> 0. No claims changed.
2026-06-04 docs: tighten DESIGN.md em-dash rule to default-zero in body copy
    Matches the actual bar (the "≤1/paragraph" version was too lax). Adds a
    grep check before shipping copy.
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2026-06-04 feat(firmware): reboot-resume + remote control for logging
    Fixes the failure mode that killed the Judge Hall run (logging stopped
    after ~10 min, likely a reboot or Wi-Fi drop, with no way to restart from
    off-campus).
    - Reboot-resume: logEnabled + runLabel persisted to NVS (Preferences),
    restored on boot. A crash/power-blip now RESUMES the same run instead
    of going silent. /log/start + /log/stop persist via applyLogCommand().
    - Remote control: device polls Apps Script doGet every 60s for
    {logging, label, seq} and applies a command only when seq increments
    (never fights the on-device web UI). Outbound HTTPS, so a run can be
    started/stopped from anywhere by editing the new `control`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
    [config.h, main.cpp]
2026-06-05 feat(security): authenticate telemetry writes with shared token
    The Apps Script /exec URL is committed in firmware/include/config.h (public
    repo), and doPost() previously appended any POST body with no auth — so anyone
    could inject rows and poison the dataset (the product's moat).
    - Firmware now sends a SHEETS_TOKEN (from gitignored secrets.h) in every POST.
    - doPost() rejects writes whose token doesn't match a SHEETS_TOKEN Script
    Property. Rollout is order-independent and lossless: endpoint accepts all
    while the property is unset, enforces strictly once it's set.
    - token is auth-only; buildRow_ ignores it, so the sheet schema is unchanged.
    Verified: esp32dev builds clean (Flash 83.7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
    [main.cpp]
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2026-06-06 feat(data): add run_id for unambiguous per-run identification
    Runs were distinguished only by the free-text condition label (collisions,
    no clean boundary, no provenance). Now each run carries a unique id.
    - Firmware: DEVICE_ID added to config.h; runId = <device_id>_<start_epoch>
    minted on run start in applyLogCommand, persisted to NVS (survives reboot
    so a resumed run keeps its id), restored in setup(), and sent in the POST
    body (also now sends device_id). Falls back to uptime millis pre-NTP.
    - Code.gs: 'run_id' appended to SCHEMA; buildRow_ writes runId_(p.run_id),
    sanitized to a safe key charset; blank for legacy rows.
    Migration when this deploys: add a 'run_id' header to cell J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
    [config.h, main.cpp]
2026-06-06 feat(data): archival — Sheet becomes ingest buffer, runs archived offline
    Pulls read-only, groups rows into runs (by run_id; legacy rows split into
    contiguous sessions via condition-change + >60min gap detection so the Fahey
    overnight run stays whole while real logging gaps surface honestly), and writes
    each completed run to a per-run CSV under a gitignored archive/ dir plus a
    runs_index.json manifest (the queryable dataset index: condition, device,
    start/end, n_rows, co2 mean/peak).
    - The active/newest run is skipped unless --all (never archives mid-flight).
    - Idempotent: a run already in the manifest with the same row count is skipped.
    - Pruning the live tab is intentionally NOT here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
2026-06-06 feat(data): Tier 1 SQLite sync + fix lexical timestamp sort
    SQLite is now the durable system of record (the moat). sqlite_sync.py unions the
    live Sheet + archived CSVs into archive/ventis.db (gitignored): readings table
    (UNIQUE device_id+timestamp -> idempotent upsert) + a runs table rebuilt each
    sync. Survives Sheet pruning because it also ingests the archive CSVs. Supports
    --no-sheet (offline) and --sql for ad hoc queries. sqlite3 is stdlib, no new deps.
    Also fixes a real data bug: Google Sheets returns UNPADDED hours ('0:59:32'), so
    the prior lexical sort placed 9am rows after 7pm rows — which faked a 9-hour gap
    and wrongly split the Fahey overnight run into two. archive_runs now sorts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
2026-06-06 feat(data): /ventis-backup orchestrator — refresh + chart + back up
    One command (refresh_backup.py) chains the data pipeline: pull telemetry ->
    SQLite sync -> archive completed runs -> charts per the Data Plotting SOP
    (plot_ventis_run.py --all) -> zip all of archive/ to OneDrive\Ventis-Backups
    (auto off-machine cloud). Charts land in archive/graphs/ and ride the backup.
    Chart step is best-effort (--no-graphs / skips on missing matplotlib) so a plot
    dep never blocks the data backup. Read-only throughout — never writes/prunes the
    Sheet. archive/ stays gitignored (the moat).
    Verified: full run -> 2568 rows, SQLite 2 runs, 2 charts, 390KB zip to OneDrive.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
2026-06-06 fix(catalog): lowercase chart filenames for case-sensitive hosts; run detail page + route
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2026-06-06 feat(library): dataset overview stats + search + About/data-dictionary + zip export
    - StatsBar: headline aggregates (runs, buildings, readings, device-hours, ASHRAE rate, peak)
    - searchRuns free-text filter + search box
    - AboutPage: methodology + data dictionary + 'Download full dataset' (jszip) export
    - datasetStats/searchRuns unit-tested (vitest); browser-verified, no console errors
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2026-06-07 fix(ci): retry transient Sheets API errors on the data-library pull (#3)
    The hourly data-library cron failed once (run 27085208176) with a bare
    gspread APIError [503] service-currently-unavailable during the Sheet pull,
    skipping the build + deploy. It self-cleared the next hour, but a single
    Google 5xx blip should not turn the whole run red.
    Wrap the two network calls in sheet_source.fetch_rows (open_by_key/worksheet
    and get_all_records) in a bounded exponential-backoff retry that fires only on
    transient statuses (429/500/502/503/504). Real 4xx config errors still fail
    fast. Adds test_sheet_source.py (recovers / gives up / no-retry-on-4xx).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
2026-06-07 fix(supabase): skip rows with unparseable timestamps on sync
    Postgres timestamptz rejects ""/garbage that SQLite (TEXT) tolerated, so the
    initial Supabase seed aborted with InvalidDatetimeFormat on the first empty
    timestamp. The real union has 6 such rows — all blank/unlabeled junk (empty
    timestamp + empty condition under legacy_unlabeled_), not real samples.
    build_reading_rows now drops any row whose timestamp won't parse (reusing
    archive_runs._parse), so only valid-timestamp readings reach Postgres. Keeps
    the (device_id, timestamp) unique upsert clean (no NULL-timestamp dup risk).
    Adds a regression test; full union now 39,680 rows / 6 runs, 0 bad timestamps.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
2026-06-07 fix(consent): default-import pg so the ESM function loads (FUNCTION_INVOCATION_FAILED) (#6)
    The function crashed at module load (platform crash, not our JSON 500 — our
    try/catch never ran). site/ is "type":"module", and `import { Client } from "pg"`
    (CJS named import) fails under ESM at runtime. Use `import pg from "pg"; const
    { Client } = pg;` — the canonical pg-in-ESM form.
2026-06-07 fix(consent): .js extension on the ESM relative import (the actual load crash) (#8)
    Vercel function log gave ground truth: ERR_MODULE_NOT_FOUND for './_validate'
    imported from consent.js — the function runs as ESM, where relative imports
    require the .js extension. Import './_validate.js' (resolves the .ts sibling at
    build, the .js at runtime). Revert the CommonJS api/package.json crutch (didn't
    take); clean ESM function = pg default-import + .js extension. Build + vitest green.
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2026-06-07 docs(plans): durability & device-hardening cold-start plan (#11)
    Track A (cold-executable, TDD): token-authed /api/ingest endpoint so the device
    can write readings straight to Supabase (removes the Sheet ceiling), reusing the
    consent function's proven pg/ESM/SSL fixes. Track B (firmware, HARDWARE-GATED w/
    explicit stop-and-handoff steps): shared-secret auth on mutating + /insight
    endpoints, Anthropic-key protection, dual-write to /api/ingest, dashboard-refresh
    heap-crash investigation. Relationships track = a sequenced action checklist kept
    in the private vault (names real contacts; public repo would leak it).
    Co-authored-by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
2026-06-11 spike(ventis): postgres.js connects to Supabase pooler from Workers runtime
    Adds postgres + wrangler deps, wrangler.toml (nodejs_compat), and a
    temporary GET probe in library/functions/api/annotate.ts. Live connection
    check deferred — needs Diego's real SUPABASE_DB_URL in library/.dev.vars
    (gitignored). Replaced by the real POST handler in the next task.
2026-06-11 feat(ventis): POST /api/annotate upserts run annotation to Supabase
    Replaces the spike probe with the production handler: validate -> resolve
    updated_by from Cf-Access header -> upsert into annotations via postgres.js
    (same on-conflict semantics as annotate.py). Live DB smoke deferred to
    Diego (.dev.vars secret); the pure logic it imports is unit-tested.
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2026-06-11 ci(ventis): deploy catalog from library/ so Pages Functions ship
    The deploy ran 'pages deploy library/dist' from repo root, so wrangler
    never saw library/functions/ — the /api/annotate Pages Function would
    not deploy. Run from workingDirectory: library with 'pages deploy' so
    wrangler picks up functions/ and wrangler.toml (nodejs_compat). Still
    --branch=main (production-only; no preview-subdomain moat leak). Bumps
    wrangler 3->4 (modern Miniflare/socket support).
2026-06-11 feat(site): add OG/Twitter share image for link previews
    Wires Claude Design's og-image.png (1200x630, real 1,111 ppm curve) into
    the head: og:image/url/site_name + image dimensions + alt, and a
    summary_large_image Twitter card. Fixes bare link previews when the site
    is shared with ResLife / Conklin / partners.
2026-06-11 docs(ventis): plan for run attributes (label scenario + annotation overrides)
    9-task plan: parse window/fan/scenario from label (fan off default, window
    blank when silent); add annotation override columns (occupancy/window/fan);
    resolve override>label in build_catalog; surface in catalog UI; backfill
    Little=2 occupants + Fahey window sequence. Occupancy parse already shipped.
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2026-06-12 fix(site): re-frame "The Proof" to the positioning canon (not fan-vs-window) (#22)
    End-session consistency check caught that the new /proof page led with the
    fan-vs-window physics point, which [[Positioning — Why Not Just Open a Window]]
    says never to show publicly ("physics framing accidentally sells the window").
    Diego's call: re-frame the copy (keep the page + proof, lead with behavior/
    comfort/automation, demote physics to credibility).
    - Headline: "We closed the window. The fan kept running. CO2 climbed anyway."
    -> "The window was open. Then it closed for the night."
    - Lede + hero subtitle now lead with the behavior gap: a free fix (the open
    window) left unused at the hours that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
2026-06-12 feat(data): robust co2_peak/co2_mean to reject deployment artifacts (#24)
    Raw MAX(co2)/AVG(co2) let boundary artifacts (sensor warm-up at deploy,
    reboot-resume, the pull) masquerade as a run's headline peak — e.g. the
    ~41h Little run reported 2109 ppm from a ~7-min startup transient that
    decayed to ~890.
    archive_runs.co2_stats() now computes:
    - co2_mean: arithmetic mean AFTER dropping the first 15 min (warm-up bias),
    with fallback to the full series on short runs.
    - co2_peak: max of a 5-min ROLLING MEAN, so a brief spike can't be the peak
    while a genuine sustained high survives.
    Wired into supabase_sync.aggregate_runs (the path build_catalog reads) and
    archive_runs._meta (manifest).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
2026-06-14 style(site): square all corners + ease-out-expo motion (§12 bolder pass)
    Move from soft to sharp across the site, reinforcing the field-report posture.
    - radius tokens --r-lg/md/sm -> 0; square all hardcoded rectangular radii (nav, buttons, icon badges, pills/tags, tooltip, hero sticker)
    - keep curved by design: device-demo phone + .dd-* internals (physical-hardware metaphor) and true circles (status dots, round avatar)
    - add --ease-out cubic-bezier(0.16,1,0.3,1); apply to nav/button transitions
    - document in DESIGN.md §5 + §12
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2026-06-14 feat(site,library): bolder pass — dial back corners, hairline borders, bigger hero
    Address feedback that the all-sharp look had too many hard corners.
    - radii dialed back from 0 to moderate (--r-lg 12 / --r-md 10 / --r-sm 8);
    pills/chips/badges restored to fully rounded; device + true circles unchanged
    - hairline-led elevation: crisper --line (0.16) + flatter resting shadows
    - bolder hero: larger DM Serif wordmark (up to 128px) + larger/heavier lede
    - mirrored across site (global.css) and library (theme.css); DESIGN.md §5 updated
    Note: site/library motion (Dodi flap/blink, scroll reveals) is correctly gated to
    prefers-reduced-motion; invisible when the OS has reduce-motion on.
    Co-Aut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
2026-06-16 fix(consent): canonical() bridges glued number-words (oneperson -> 1person) (#25)
    reconcile_consent.canonical() mapped number-words to digits only when the word
    was its own token. A label like french_window_oneperson (glued) stayed
    '...oneperson' while the consent form's french_window_one_person became
    '...1person', so the matcher refused to link them and the submission orphaned
    (real case: French run 2026-06-14, consent_submissions id=4).
    Add _split_glued_numword(): peels a leading number-word off a token ONLY when the
    remainder is a recognized occupancy word, so 'oneperson'->['one','person'] but
    'tenant' stays intact (never '10ant'). Occupancy counts remain distinct
    (oneperson != twoperso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
